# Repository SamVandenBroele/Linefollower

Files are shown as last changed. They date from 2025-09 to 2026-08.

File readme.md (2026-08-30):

# Line Follower Robot

Dit project bevat het ontwerp en de realisatie van een snelle autonome line-following robot voor het Syntheseproject Automatisering.

Het gerealiseerde prototype is een Plan-B-uitvoering en gebruikt zes analoge reflectiesensoren om een zwarte lijn op een witte ondergrond te volgen.

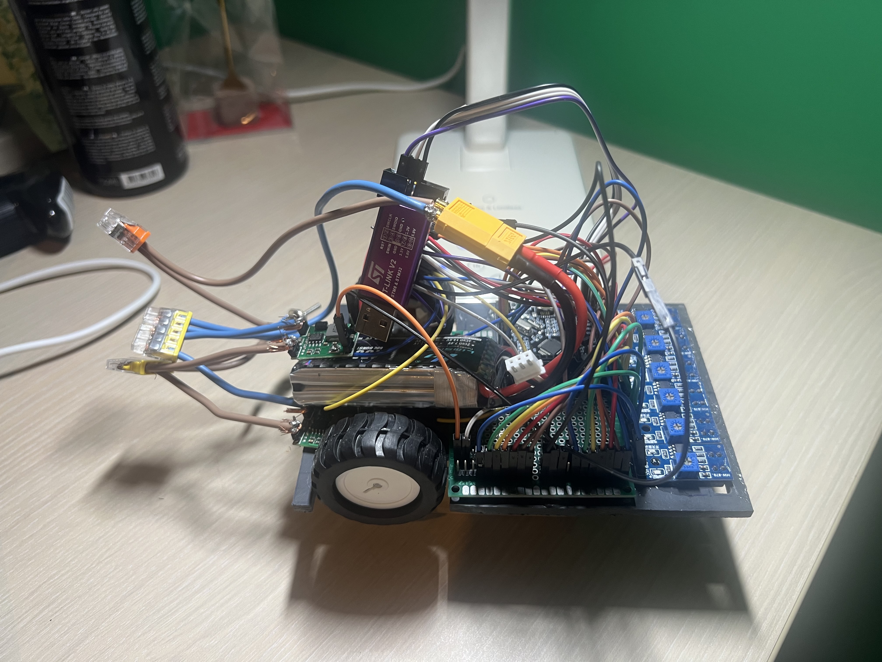
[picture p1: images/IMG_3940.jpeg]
Line Follower Robot


## Specificaties

- Microcontroller: STM32F103C8T6
- Motoren: 2 × GA12-N20, 6 V, 300 rpm
- Motordriver: TB6612FNG dubbele H-brug
- Lijnsensoren: 6 × TCRT5000
- Batterij: 2S LiPo, 7,4 V, 1500 mAh, 45C
- Voedingsregeling: 2 × MP1584EN buckconverter
- Logicaspanning: 3,3 V
- Motorvoeding: 5 V
- Wielen: diameter 44 mm
- Chassis: PVC, 4 mm dik
- Chassisbreedte: 100 mm
- Chassislengte: 147 mm
- Bluetoothmodule: HM-10
- EEPROM: 24LC256

## Werking

De zes TCRT5000-sensoren worden analoog uitgelezen door de ADC van de STM32.

Op basis van de gemeten sensorwaarden wordt de positie van de zwarte lijn bepaald. De STM32 past vervolgens via PWM de snelheid van beide motoren onafhankelijk aan.

De lijncorrectie is proportioneel met de gemeten afwijking van de lijn. In de definitieve software wordt een proportionele correctiefactor van `0,50` gebruikt.

De software maakt onderscheid tussen rechte stukken en bochten. Op rechte stukken wordt een hogere basissnelheid gebruikt en in bochten wordt deze snelheid verlaagd.

Bij detectie van een brede zwarte zone wordt deze als kruispunt beschouwd. De normale lijncorrectie wordt dan tijdelijk uitgeschakeld en beide motoren krijgen dezelfde snelheid, zodat de robot rechtdoor over het kruispunt rijdt.

## Repository

De belangrijkste onderdelen van het project zijn terug te vinden in de volgende mappen:

- `bill of materials` – volledige onderdelenlijst en voedingsverdeling
- `code/finaal` – finale software van de line follower
- `code/proof of concepts/hbridge` – proof of concept van de motorsturing
- `code/proof of concepts/sensor` – proof of concept van de zes lijnsensoren
- `datasheets` – datasheets van de gebruikte componenten
- `gebruiksaanwijzing` – gebruiksaanwijzing van de robot
- `images` – foto's van het gerealiseerde prototype
- `instructable` – stappenplan om de robot na te bouwen
- `technische tekeningen/elektronisch` – elektronisch schema
- `technische tekeningen/mechanisch` – mechanisch ontwerp

## Line-following software

De belangrijkste parameters van de definitieve werkende software zijn:

- snelheid recht stuk: `300`
- snelheid bocht: `150`
- grenswaarde bochtdetectie: `120`
- maximale motorsnelheid in software: `600`
- proportionele correctiefactor: `0,50`
- kruispuntdetectie: minimaal `3` sensoren detecteren zwart
- kruispunt vrijgave: `300` meetcycli

Alle zes lijnsensoren worden door de STM32 uitgelezen.

In de huidige finale software worden de eerste vijf sensoren gebruikt voor de berekening van de lijnpositie en de kruispuntdetectie.

De zesde sensor wordt wel uitgelezen, maar niet meegenomen in deze berekeningen wegens een foutieve hoge meetwaarde op wit in de gemonteerde opstelling.

## Motorsturing

De twee GA12-N20 DC-motoren worden onafhankelijk aangestuurd via de TB6612FNG.

De snelheid van beide motoren wordt geregeld met PWM.

Bij normale lijnvolging wordt de motorsnelheid bepaald volgens:

`motor A = basissnelheid + correctie`

`motor B = basissnelheid - correctie`

waarbij:

`correctie = 0,50 × lijnpositie`

## Kruispunten

Wanneer minimaal drie van de gebruikte lijnsensoren tegelijk zwart detecteren, wordt dit als een brede zwarte zone of kruispunt beschouwd.

Tijdens de kruispuntmodus:

- wordt de normale lijncorrectie tijdelijk uitgeschakeld;
- krijgen beide motoren dezelfde snelheid;
- rijdt de robot rechtdoor;
- wordt pas na meerdere normale meetcycli terug overgeschakeld naar de gewone lijnregeling.

Met de definitieve instellingen neemt het prototype het kruispunt correct rechtdoor.

## Huidige uitvoering

Het Plan-B-prototype wordt in- en uitgeschakeld met een bistabiele tuimelschakelaar.

Als derde steunpunt onder het chassis wordt een LEGO-gezichtje gebruikt dat reeds thuis beschikbaar was en als glijsteun over het parcours beweegt.

De HM-10 Bluetoothmodule en 24LC256 EEPROM zijn voorzien in het elektronische ontwerp, maar worden niet actief gebruikt door de huidige finale lijnvolgsoftware.

Het uiteindelijke prototype heeft geen afzonderlijke START/STOP-drukknop en geen Power-on LED.

De parameters van de lijnregeling werden experimenteel afgesteld op het uiteindelijke prototype.

Met de definitieve instellingen volgt de robot de lijn stabiel, neemt hij het kruispunt correct rechtdoor en kan hij meerdere volledige rondes na elkaar afleggen.

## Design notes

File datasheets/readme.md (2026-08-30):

# Datasheets

Deze map bevat de beschikbare datasheets en technische documentatie van de belangrijkste componenten die gebruikt worden in de Line Following Robot.

## Componenten

De volgende documentatie is opgenomen:

- STM32F103C8T6 microcontroller
- TB6612FNG dubbele motordriver
- TCRT5000 reflectieve optische sensor
- HM-10 Bluetoothmodule
- GA12-N20 6 V 300 rpm DC-reductiemotor
- 24LC256 I²C EEPROM

## TCRT5000-sensormodule

De TCRT5000-sensoren die in dit project gebruikt worden, zijn complete sensormodules met een TCRT5000 reflectieve optische sensor en bijkomende elektronica, waaronder een LM393-comparator.

Er was geen officiële datasheet beschikbaar voor de volledige gebruikte sensormodule.

Daarom is de datasheet van de TCRT5000-sensor zelf opgenomen als technische referentie.

In het uiteindelijke prototype wordt de analoge uitgang A0 van de sensormodule gebruikt.

## GA12-N20 6 V 300 rpm motor

Voor de exacte GA12-N20 6 V 300 rpm motor die in dit project gebruikt wordt, was geen officiële datasheet beschikbaar.

Het opgenomen GA12-N20-document wordt daarom gebruikt als algemene technische referentie voor deze motorfamilie en beschrijft niet noodzakelijk exact de gebruikte 300 rpm-variant.

## MP1584EN buckconverter

Voor de voedingsregeling worden twee instelbare MP1584EN DC-DC step-down buckconverters gebruikt.

De batterijspanning van de 2S LiPo wordt hiermee verlaagd naar:

- 3,3 V voor de 3,3 V-logica;
- 5 V voor de STM32 en de motorvoeding.

De gebruikte modules zijn gebaseerd op de MP1584EN en hebben een instelbare uitgangsspanning.

Er is momenteel geen aparte datasheet van de gebruikte MP1584EN-module opgenomen in deze map.

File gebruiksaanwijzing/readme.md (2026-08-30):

# Gebruiksaanwijzing

Deze gebruiksaanwijzing beschrijft het gebruik van het Plan-B-prototype van de snelle line-following robot.

## Voeding

De robot wordt gevoed door een 2S LiPo-batterij van 7,4 V nominaal.

De batterij wordt via de XT60-connector aangesloten op de robot. De hoofdvoeding wordt in- en uitgeschakeld met de tuimelschakelaar.

De voedingsspanningen worden met twee MP1584EN buckconverters geregeld:

- 5 V voor de STM32 en de motorvoeding via de TB6612FNG
- 3,3 V voor de overige 3,3 V-logica
- de TCRT5000-sensoren worden gevoed via de 3,3 V-uitgang van de STM32

Alle subsystemen gebruiken een gemeenschappelijke GND.

## Inschakelen

1. Plaats de robot op het parcours met de sensoren boven de zwarte lijn.
2. Controleer of de LiPo-batterij correct is aangesloten.
3. Zet de hoofdschakelaar aan.
4. De STM32 start het lijnvolgprogramma automatisch.
5. De robot begint de zwarte lijn te volgen.

## Lijnvolging

De robot beschikt over zes TCRT5000-reflectiesensoren.

De analoge uitgangen van de sensoren worden uitgelezen via de ADC van de STM32F103C8T6.

De software bepaalt aan de hand van de sensorwaarden de positie van de zwarte lijn. Met een proportionele regeling wordt vervolgens het snelheidsverschil tussen de linker- en rechtermotor bepaald.

Op rechte stukken wordt een hogere basissnelheid gebruikt. Wanneer een grotere afwijking van de lijn wordt gemeten, wordt de basissnelheid verlaagd zodat de robot stabieler door bochten kan rijden.

In de huidige software worden vijf van de zes uitgelezen sensoren gebruikt voor de berekening van de lijnpositie. De zesde sensor wordt voorlopig niet meegenomen omdat deze in de huidige opstelling op een witte ondergrond foutief hoge ADC-waarden kan geven.

## Kruispunten

De robot is geprogrammeerd om op een kruispunt rechtdoor te rijden.

Wanneer minstens drie van de gebruikte sensoren gelijktijdig zwart detecteren, wordt dit beschouwd als een brede zwarte zone en wordt de kruispuntmodus geactiveerd.

Tijdens deze modus:

- wordt de normale lijncorrectie tijdelijk uitgeschakeld;
- worden beide motoren met dezelfde snelheid aangestuurd;
- rijdt de robot rechtdoor over het kruispunt.

Wanneer gedurende meerdere opeenvolgende meetcycli opnieuw een normale lijn wordt waargenomen, schakelt de robot automatisch terug naar de normale lijnvolging.

## Motorsturing

De robot gebruikt twee GA12-N20 DC-motoren.

Beide motoren worden onafhankelijk aangestuurd via een TB6612FNG dubbele H-brug.

De snelheid van de motoren wordt geregeld met PWM. Door het snelheidsverschil tussen de linker- en rechtermotor aan te passen kan de robot naar links of rechts corrigeren.

## Instellingen

De belangrijkste instellingen van de huidige finale software zijn:

- rechte snelheid: `220`
- bochtsnelheid: `150`
- bochtdrempel: `120`
- maximale motorsnelheid: `600`
- proportionele correctiefactor: `0,75`
- kruispuntdetectie: minimaal `3` zwarte sensoren

Deze waarden zijn experimenteel afgestemd op het Plan-B-prototype en het gebruikte testparcours.

## Uitschakelen

Na gebruik wordt de robot uitgeschakeld met de hoofdschakelaar.

Wanneer de robot langere tijd niet gebruikt wordt, wordt de LiPo-batterij losgekoppeld van de robot.

## LiPo-batterij

Voor het opladen van de 2S LiPo-batterij moet een geschikte LiPo-balanslader gebruikt worden.

De gebruikte batterij heeft:

- nominale spanning: 7,4 V
- volledig geladen spanning: 8,4 V
- capaciteit: 1500 mAh
- ontlaadfactor: 45C

Een beschadigde of opgezwollen LiPo-batterij mag niet gebruikt of opgeladen worden.

## Huidige beperkingen

De HM-10 Bluetoothmodule, EEPROM en externe START/STOP-functionaliteit zijn voorzien in het elektronische ontwerp, maar zijn niet geïntegreerd in de huidige finale lijnvolgsoftware.

Er wordt in het huidige Plan-B-prototype geen Power-on LED gebruikt.

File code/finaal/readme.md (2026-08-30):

# Finale code

Deze map bevat de finale software van het Plan-B-prototype van de snelle line-following robot.

De software is geschreven voor de STM32F103C8T6 en verzorgt de uitlezing van de lijnsensoren, de aansturing van beide motoren en de detectie van kruispunten.

## Bestandsstructuur

### Inc

- `sensors.h` – definities en functies voor de lijnsensoren
- `motors.h` – definities en functies voor de motorsturing
- `bluetooth.h` – functies voorzien voor de HM-10 Bluetoothmodule
- `eeprom.h` – functies voorzien voor de 24LC256 EEPROM

### Src

- `main.c` – hoofdprogramma en lijnvolgalgoritme
- `sensors.c` – ADC-uitlezing en berekening van de lijnpositie
- `motors.c` – aansturing van de TB6612FNG en beide motoren
- `bluetooth.c` – functies voor Bluetoothcommunicatie
- `eeprom.c` – functies voor EEPROM-communicatie

## Lijnvolging

De robot gebruikt zes TCRT5000-reflectiesensoren.

Alle zes sensoren worden analoog uitgelezen door de ADC van de STM32.

In de huidige finale lijnregeling worden de eerste vijf sensoren gebruikt voor:

- het berekenen van de lijnpositie;
- het detecteren van een kruispunt.

De zesde sensor wordt wel uitgelezen, maar niet meegenomen in de huidige regeling omdat deze in de gemonteerde opstelling een foutief hoge meetwaarde op wit gaf.

De positie van de zwarte lijn wordt bepaald aan de hand van een gewogen gemiddelde van de sensorwaarden.

Op basis van deze lijnpositie wordt een proportionele correctie berekend:

`correctie = 0,50 × lijnpositie`

De motorsnelheden worden vervolgens bepaald als:

`motor A = basissnelheid + correctie`

`motor B = basissnelheid - correctie`

Hierdoor wordt de robot terug naar het midden van de zwarte lijn gestuurd.

## Snelheidsregeling

De definitieve instellingen zijn:

- snelheid op een recht stuk: `300`
- snelheid in een bocht: `150`
- grenswaarde voor bochtdetectie: `120`
- maximale motorsnelheid in software: `600`
- proportionele correctiefactor: `0,50`

Wanneer de absolute waarde van de lijnpositie groter wordt dan `120`, wordt de lagere bochtsnelheid gebruikt.

Hierdoor rijdt de robot sneller op rechte stukken en trager wanneer een grotere stuurcorrectie nodig is.

## Kruispuntdetectie

Een brede zwarte zone wordt als kruispunt beschouwd wanneer minimaal drie van de gebruikte lijnsensoren tegelijk zwart detecteren.

Wanneer een kruispunt wordt gedetecteerd:

1. wordt de normale lijncorrectie tijdelijk uitgeschakeld;
2. krijgen beide motoren dezelfde snelheid;
3. rijdt de robot rechtdoor over het kruispunt;
4. blijft de kruispuntmodus actief tot opnieuw gedurende meerdere meetcycli een normale lijn wordt waargenomen.

De gebruikte instellingen zijn:

- minimaal aantal zwarte sensoren: `3`
- aantal cycli voor het verlaten van de kruispuntmodus: `300`

## Motorsturing

De twee GA12-N20 DC-motoren worden aangestuurd met een TB6612FNG dubbele H-brug.

De snelheid wordt geregeld met PWM.

De gebruikte aansluitingen zijn:

### Motor A

- PWMA → PA8
- AIN1 → PB13
- AIN2 → PB12

### Motor B

- PWMB → PB3
- BIN1 → PB15
- BIN2 → PA9

### TB6612FNG

- STBY → PB14
- VCC → 3,3 V
- VM → 5 V
- GND → gemeenschappelijke GND

## Sensoren

De gebruikte analoge ingangen zijn:

- S0 → PA0
- S1 → PA1
- S2 → PA4
- S3 → PA5
- S4 → PA6
- S5 → PA7

De zes sensoren worden gevoed via de 3,3 V-uitgang van de STM32.

## Huidige uitvoering

De huidige finale software bevat de werkende functies die nodig zijn voor het Plan-B-prototype:

- analoog uitlezen van zes lijnsensoren;
- bepalen van de lijnpositie;
- proportionele lijncorrectie;
- afzonderlijke PWM-aansturing van beide motoren;
- vertragen in bochten;
- detecteren van kruispunten;
- rechtdoor rijden over kruispunten.

De parameters werden experimenteel afgesteld op het uiteindelijke prototype.

Met de definitieve instellingen `300` voor rechte stukken, `150` voor bochten en een proportionele correctiefactor van `0,50` volgt de robot de lijn stabiel en kan hij meerdere volledige rondes na elkaar afleggen.

Ook het kruispunt wordt met deze instellingen correct rechtdoor genomen.

De HM-10 Bluetoothmodule en 24LC256 EEPROM zijn voorzien in het elektronische ontwerp, maar worden niet actief gebruikt door de huidige finale lijnvolgsoftware.

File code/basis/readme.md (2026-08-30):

# Basisprogramma

Deze map was voorzien voor het basisprogramma waarin verschillende algemene functies van de robot samen geïntegreerd konden worden.

Het oorspronkelijke project voorzag onder andere:

- instelbare parameters via seriële communicatie;
- opslag van parameters in EEPROM;
- START/STOP via een externe interrupt;
- draadloze communicatie.

Deze functies zijn niet volledig samengebracht in één afzonderlijk basisprogramma.

Voor het uiteindelijke Plan-B-prototype werd de ontwikkeling voornamelijk gericht op de essentiële functies voor een werkende line-following robot:

- uitlezen van zes analoge TCRT5000-lijnsensoren;
- aansturen van twee DC-motoren via de TB6612FNG;
- PWM-snelheidsregeling;
- berekenen van de lijnpositie;
- corrigeren van de rijrichting;
- detecteren en rechtdoor rijden op kruispunten.

De daadwerkelijk gebruikte software van het uiteindelijke prototype is terug te vinden in:

`code/finaal`

Afzonderlijke werkende tests van de lijnsensoren en H-brug zijn terug te vinden onder:

`code/proof of concepts`

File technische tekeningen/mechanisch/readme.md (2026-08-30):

# Mechanisch ontwerp

Deze map bevat het mechanische ontwerp van het Plan-B-prototype van de snelle line-following robot.

## Chassis

Het chassis is vervaardigd uit een PVC-plaat.

Belangrijkste afmetingen:

- Materiaal: PVC
- Dikte: 4 mm
- Breedte: 100 mm
- Lengte: 147 mm
- Uitsparingen voor de wielen: 20 × 47 mm
- Opening voor de sensoren: 90 × 5 mm
- Voorste rand: 5 mm
- Achterste rand: 5 mm

## Aandrijving

De robot wordt aangedreven door twee GA12-N20 DC-reductiemotoren van 6 V en 300 rpm.

Op beide motoren is een rubberen wiel met een diameter van 44 mm gemonteerd.

## Lijnsensoren

Aan de voorzijde van het chassis zijn zes TCRT5000-reflectiesensoren naast elkaar geplaatst.

De sensoren zijn naar de ondergrond gericht en worden gebruikt om de zwarte lijn op de witte ondergrond te detecteren.

## Elektronica

Op het chassis zijn onder andere de volgende onderdelen geplaatst:

- STM32F103C8T6 development board
- TB6612FNG dubbele H-brug
- twee MP1584EN buckconverters
- 2S LiPo-batterij
- HM-10 Bluetoothmodule
- 24LC256 EEPROM
- prototypeprintplaat
- zes TCRT5000-lijnsensoren

## Derde steunpunt

Als derde steunpunt onder het chassis wordt een LEGO-gezichtje gebruikt dat reeds thuis beschikbaar was.

Het LEGO-onderdeel vormt een eenvoudige glijsteun en glijdt tijdens het rijden over het parcours.

## Mechanische tekening

Het bestand `Mechanical_Design.png` toont de afmetingen van het chassis en de voorziene plaatsing van de belangrijkste onderdelen.

De uiteindelijke fysieke plaatsing van kleine elektronische componenten kan licht afwijken van de schematische voorstelling.

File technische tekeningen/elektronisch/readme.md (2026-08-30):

## Elektronisch schema

Het schema bevat:
- STM32F103C8T6
- 6 × TCRT5000 lijnsensor
- TB6612FNG H-brug
- HM-10 Bluetoothmodule
- 24LC256 EEPROM
- START/STOP-drukknop
- 3,3 V en 5 V voedingsregeling
- beide GA12-N20 motoren

De Electrical Rules Check (ERC) geeft 0 overtredingen.

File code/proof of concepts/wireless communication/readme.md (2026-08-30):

# Draadloze communicatie proof of concept

Voor dit project was een proof of concept voor draadloze communicatie voorzien met behulp van een HM-10 Bluetoothmodule.

De HM-10 Bluetoothmodule is fysiek voorzien in het elektronische ontwerp en aangesloten op de STM32 via USART2:

- STM32 PA2 (USART2_TX) → HM-10 RX
- STM32 PA3 (USART2_RX) ← HM-10 TX

Een werkende proof of concept voor draadloze communicatie werd niet gerealiseerd voor het uiteindelijke Plan-B-prototype.

Draadloze communicatie wordt daarom niet gebruikt door de huidige finale lijnvolgsoftware.

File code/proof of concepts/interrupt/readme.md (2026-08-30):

# Start/stop interrupt proof of concept

Voor dit project was een proof of concept voorzien waarbij een START/STOP-drukknop via een hardware-interrupt wordt uitgelezen.

Deze proof of concept werd niet gerealiseerd voor het uiteindelijke Plan-B-prototype.

Het uiteindelijke prototype beschikt niet over een afzonderlijke START/STOP-drukknop. De robot wordt in- en uitgeschakeld met de bistabiele hoofdschakelaar.

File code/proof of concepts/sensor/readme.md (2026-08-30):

# Sensoren proof of concept

## Testresultaten

De zes TCRT5000-lijnsensoren werden afzonderlijk uitgelezen via de 12-bit ADC van de STM32F103C8T6. Hiervoor wordt de analoge uitgang (A0) van iedere sensormodule gebruikt.

### Meting op witte ondergrond

Bij een witte ondergrond werden ADC-waarden tussen ongeveer 200 en 336 gemeten.

### Meting op zwarte ondergrond

Bij een zwarte ondergrond werden ADC-waarden tussen ongeveer 1700 en 3769 gemeten.

### Conclusie

De test toont aan dat alle zes TCRT5000-sensoren onafhankelijk via de ADC kunnen worden uitgelezen. Er is een duidelijk verschil tussen de gemeten waarden op een witte en een zwarte ondergrond.

De STM32F103C8T6 beschikt over een 12-bit ADC met een bereik van 0 tot 4095. De gemeten waarden benutten een groot deel van dit bereik, met waarden tot 3769 op de zwarte ondergrond.

Voor deze proof of concept worden de ruwe ADC-waarden rechtstreeks weergegeven. Er wordt geen normalisatie of interpolatie toegepast.

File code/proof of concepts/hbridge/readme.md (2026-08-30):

# H-Bridge proof of concept

# H-Bridge proof of concept

Deze proof of concept toont aan dat de TB6612FNG dubbele H-brug correct kan worden aangestuurd door de STM32F103C8T6.

## Doel

Het doel van deze test is controleren of:

- beide GA12-N20 DC-motoren kunnen worden aangestuurd;
- beide motoren onafhankelijk kunnen draaien;
- de draairichting softwarematig kan worden gewijzigd;
- de motorsnelheid met PWM kan worden geregeld;
- de STBY-functie van de TB6612FNG correct werkt.

## Gebruikte componenten

- STM32F103C8T6 development board
- TB6612FNG dubbele H-brug
- 2 × GA12-N20 6 V DC-motor, 300 rpm
- 5 V buck converter
- 3,3 V buck converter
- 2S 7,4 V LiPo-batterij

## Aansluitingen

### Motor A

- PWMA → PA8
- AIN1 → PB13
- AIN2 → PB12
- AO1/AO2 → linker motor

### Motor B

- PWMB → PB3
- BIN1 → PB15
- BIN2 → PA9
- BO1/BO2 → rechter motor

### H-brug

- STBY → PB14
- VCC → 3,3 V
- VM → 5 V
- GND → gemeenschappelijke GND

## Werking

De STM32 genereert PWM-signalen voor PWMA en PWMB. Hiermee wordt de gemiddelde spanning over de motoren en dus hun snelheid geregeld.

AIN1/AIN2 en BIN1/BIN2 bepalen de draairichting van respectievelijk motor A en motor B.

Via de STBY-ingang kan de volledige motordriver worden geactiveerd of in standby worden geplaatst.

De software gebruikt een snelheidswaarde van -1000 tot +1000:

- positieve waarde → vooruit;
- negatieve waarde → achteruit;
- 0 → motor gestopt.

## Testresultaat

De proof of concept werd succesvol uitgevoerd.

- Beide motoren draaien.
- Beide motoren kunnen onafhankelijk worden aangestuurd.
- De draairichting kan softwarematig worden gewijzigd.
- De snelheid kan met PWM worden geregeld.
- Beide motoren kunnen gelijktijdig worden aangestuurd.
- De TB6612FNG werkt correct in combinatie met de STM32F103C8T6.

Deze H-brugsturing wordt verder gebruikt in de finale line-following robot.

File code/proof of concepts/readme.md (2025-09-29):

# Proof of Concepts

Een proof of concept is een combinatie van minimale hard- en software om eenvoudig aan te tonen dat iets werkt.  
Proof of concepts kunnen enerzijds als eerste poging dienen om een bepaald onderdeel van het project werkend te krijgen. Anderzijds kunnen ze tijdens het debuggen van het finale project dienen als test om eventuele hardware problemen te elimineren bij onduidelijke problemen.
<br />  
<br />
Een proof of concept bestaat uit
* een elektronisch schema (indien van toepassing)
* minimale code om de voorop gestelde zaken te demonstreren
* minimale uitleg / aandachtspunten
<br />
De elektronische schakelingen van de proof of concepts komen bij voorkeur overeen met deze van de uiteindelijke linefollower, zodat de code zonder aanpassingen op het finale project kan draaien.

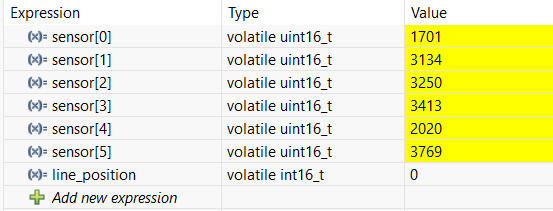
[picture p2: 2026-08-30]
code/proof of concepts/sensor/ZWART.png

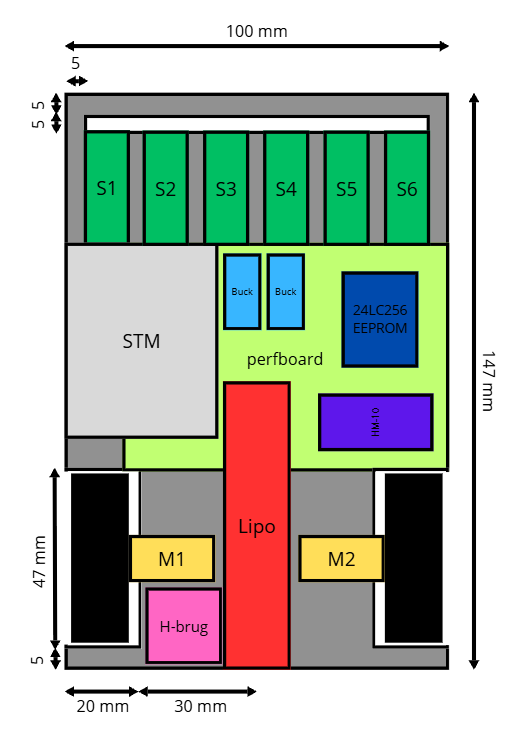
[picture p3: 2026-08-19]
technische tekeningen/mechanisch/Mechanical_Design.png

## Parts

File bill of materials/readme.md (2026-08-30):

# Bill of Materials

Deze Bill of Materials bevat de onderdelen die gebruikt worden voor het Plan-B-prototype van de snelle line-following robot.

| Nr. | Component | Type / specificatie | Aangekocht | Gebruikt | Kostprijs verpakking | Kost in project | Opmerking |
|---:|---|---|---:|---:|---:|---:|---|
| 1 | Dubbele motordriver | TB6612FNG breakoutmodule | 1 | 1 | €4,61 | €4,61 | Stuurt beide GA12-N20 DC-motoren aan |
| 2 | Dupont jumperdraden | 10 cm, diverse stekkertypes | 1 set | n.v.t. | €1,91 | €1,91 | Gebruikt voor het Plan-B-prototype |
| 3 | Infraroodreflectiesensor | TCRT5000-module met VCC, GND, D0 en A0 | 10 | 6 | €3,89 | €2,33 | Zes sensoren gemonteerd; analoge uitgang A0 wordt gebruikt |
| 4 | Microcontrollerbord | STM32F103C8T6 development board | 1 | 1 | €4,69 | €4,69 | Centrale besturing van de robot |
| 5 | Bluetoothmodule | HM-10 BLE 4.0 | 1 | 1 | €3,14 | €3,14 | Fysiek voorzien; draadloze communicatie is niet geïntegreerd in de huidige finale software |
| 6 | Printkroonsteen | KF301, 2-polig, steek 5,0 mm | 50 | ca. 4 | €0,88 | €0,07 | Voor motor- en voedingsaansluitingen |
| 7 | Aan-uitschakelaar | GOOBAY 10013, mini-tuimelschakelaar, ON-OFF, 3 A / 125 V | 2 | 1 | €1,22 | €0,61 | Bistabiele hoofdschakelaar voor het in- en uitschakelen van de batterijvoeding |
| 8 | DC-DC buckconverter | DollaTek MP1584EN, instelbaar, 4,5–28 V ingang, 0,8–20 V uitgang, max. 3 A | 5 | 2 | €4,99 | €2,00 | Eén ingesteld op 3,3 V voor de logica en één ingesteld op 5 V voor STM32 en motorvoeding |
| 9 | Robotwiel | Rubber wiel, diameter 44 mm, geschikt voor N20-as | 2 | 2 | €0,52 | €0,52 | Aandrijfwielen |
| 10 | DC-reductiemotor | GA12-N20, 6 V, 300 rpm | 2 | 2 | €3,60 | €3,60 | Aandrijving van de robot |
| 11 | Batterijconnector | XT60 mannelijk en vrouwelijk | 2 sets | 1 set | €2,38 | €1,19 | Afneembare verbinding tussen LiPo en robot |
| 12 | LiPo-batterij | 2S, 7,4 V, 1500 mAh, 45C | 1 | 1 | €7,91 | €7,91 | Nominaal 7,4 V; maximaal 8,4 V volledig geladen |
| 13 | Pinheaders | 2,54 mm male headers | 10 strips | n.v.t. | €0,68 | €0,68 | Voor modulaire elektrische aansluitingen |
| 14 | Glijsteun | LEGO-gezichtje | - | 1 | - | €0,00 | Reeds in bezit; gebruikt als derde steunpunt onder het chassis |
| 15 | Prototypeprintplaat | Dubbelzijdig protoboard, 6 × 8 cm | 3 | 1 | €2,90 | €0,97 | Printplaat voor de Plan-B-elektronica |
| 16 | Chassismateriaal | PVC-plaat, 4 mm, 100 × 200 mm | 1 | 1 | €4,13 | €4,13 | Basisplaat van de robot |
| 17 | EEPROM | 24LC256-I/P, 256 Kbit (32 KB), I²C, DIP-8 | 2 | 1 | €1,90 | €0,95 | Fysiek voorzien; niet geïntegreerd in de huidige finale lijnvolgsoftware |
| 18 | I²C pull-upweerstand | Metaalfilmweerstand, 4,7 kΩ | 10 | 2 | €0,35 | €0,07 | Pull-upweerstanden voor SDA en SCL van de I²C-bus |
| 19 | Ontkoppelcondensator | Keramisch, 100 nF, KERKO 100N | 10 | 1 | €0,40 | €0,04 | Voedingsontkoppeling bij de EEPROM |
| 20 | Start/stop-drukknop | Momentary tactile pushbutton, 6 × 6 mm | - | 0 | - | €0,00 | Niet gemonteerd op het uiteindelijke Plan-B-prototype |
| 21 | Power-on LED | Losse LED, THT | - | 0 | - | €0,00 | Niet gemonteerd op het uiteindelijke Plan-B-prototype |
| 22 | LED-serieweerstand | 1 kΩ, THT | - | 0 | - | €0,00 | Niet gebruikt op het uiteindelijke Plan-B-prototype |

## Voedingsverdeling

De robot wordt gevoed door een 2S LiPo-batterij van 7,4 V nominaal en maximaal 8,4 V bij volledige lading.

De voedingsverdeling is als volgt:

- LiPo-batterij → hoofdschakelaar → beide buckconverters
- Buckconverter 1 → **3,3 V**
  - TB6612FNG VCC
  - 24LC256 EEPROM
  - HM-10 Bluetoothmodule
  - I²C pull-upweerstanden
- Buckconverter 2 → **5 V**
  - STM32F103C8T6 development board
  - TB6612FNG VM / motorvoeding
- STM32 3,3 V-uitgang → zes TCRT5000-lijnsensoren
- TB6612FNG → beide GA12-N20 DC-motoren
- Alle subsystemen gebruiken een gemeenschappelijke GND

## Bediening

Het huidige Plan-B-prototype wordt in- en uitgeschakeld met een bistabiele tuimelschakelaar.

Als derde steunpunt onder het chassis wordt een LEGO-gezichtje gebruikt dat reeds thuis beschikbaar was. Dit werkt als eenvoudige glijsteun tijdens het rijden.

## Kostenoverzicht

| Omschrijving | Bedrag |
|---|---:|
| Totale aankoopprijs van de in deze BOM opgenomen onderdelen | €50,10 |
| Geschatte kost van gebruikte onderdelen in één robot | ca. €40,22 |

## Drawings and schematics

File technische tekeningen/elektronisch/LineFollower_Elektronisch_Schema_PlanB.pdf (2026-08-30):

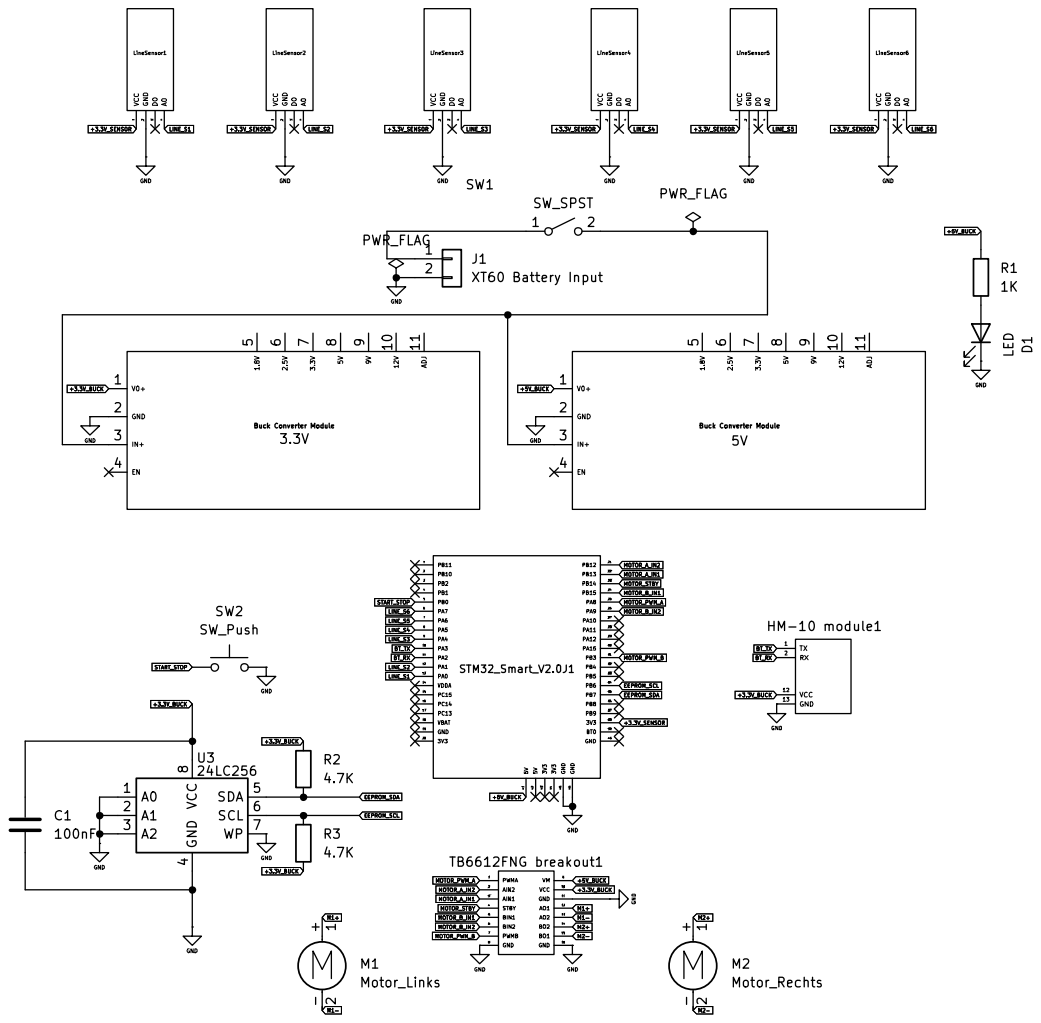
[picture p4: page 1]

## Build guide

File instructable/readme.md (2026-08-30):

# Instructable

Dit stappenplan beschrijft hoe het Plan-B-prototype van de snelle line-following robot kan worden opgebouwd.

Voor de gebruikte componenten wordt verwezen naar de Bill of Materials. Het elektronische schema en de mechanische tekeningen zijn terug te vinden in de map `technische tekeningen`.

## Stap 1 – Verzamel de componenten

Verzamel de componenten uit de Bill of Materials.

De belangrijkste onderdelen zijn:

- STM32F103C8T6 development board
- TB6612FNG dubbele H-brug
- 6 × TCRT5000-reflectiesensor
- 2 × GA12-N20 6 V 300 rpm DC-motor
- 2 × robotwiel van 44 mm
- 2S LiPo-batterij van 7,4 V
- XT60-connector
- 2 × MP1584EN buckconverter
- tuimelschakelaar
- prototypeprintplaat
- PVC-chassis
- Dupont jumperdraden
- HM-10 Bluetoothmodule
- 24LC256 EEPROM
- LEGO-gezichtje als glijsteun

Het LEGO-gezichtje was reeds thuis beschikbaar en wordt gebruikt als derde steunpunt van de robot. Het glijdt tijdens het rijden over het parcours.

## Stap 2 – Bouw het chassis

Maak het chassis uit een PVC-plaat van 4 mm dik.

Monteer vervolgens:

1. beide GA12-N20 motoren;
2. beide aandrijfwielen;
3. het LEGO-gezichtje als glijsteun en derde steunpunt;
4. de sensoropstelling aan de voorzijde;
5. de elektronische componenten op het chassis.

Gebruik de mechanische tekeningen in de repository als referentie voor de afmetingen en plaatsing van de onderdelen.

## Stap 3 – Monteer de lijnsensoren

Monteer zes TCRT5000-sensoren naast elkaar aan de voorzijde van de robot.

De sensoren moeten naar de ondergrond gericht zijn en voldoende dicht boven het parcours geplaatst worden om een duidelijk verschil tussen zwart en wit te meten.

Van iedere TCRT5000-module wordt de analoge uitgang `A0` gebruikt.

De digitale uitgang `D0` wordt niet gebruikt.

## Stap 4 – Bouw de voeding

Sluit de 2S LiPo-batterij via de XT60-connector en de tuimelschakelaar aan op de voedingsverdeling.

Gebruik twee MP1584EN buckconverters.

Stel vóór het aansluiten van de elektronica de uitgangsspanningen met een multimeter af:

- buckconverter 1: 3,3 V
- buckconverter 2: 5 V

De 3,3 V-buckconverter voedt de 3,3 V-logica.

De 5 V-buckconverter voedt de STM32 en de motorvoeding van de TB6612FNG.

De zes TCRT5000-sensoren worden gevoed via de 3,3 V-uitgang van de STM32.

Alle onderdelen moeten een gemeenschappelijke GND hebben.

## Stap 5 – Sluit de STM32 en sensoren aan

Verbind de analoge uitgangen van de zes TCRT5000-sensoren met de STM32:

- sensor S0 → PA0
- sensor S1 → PA1
- sensor S2 → PA4
- sensor S3 → PA5
- sensor S4 → PA6
- sensor S5 → PA7

Verbind de voedingsaansluitingen van de sensoren met de 3,3 V-uitgang van de STM32 en met GND.

## Stap 6 – Sluit de TB6612FNG aan

Sluit de TB6612FNG aan op de STM32.

De gebruikte stuursignalen zijn:

- PWMA → PA8
- AIN1 → PB13
- AIN2 → PB12
- STBY → PB14
- PWMB → PB3
- BIN1 → PB15
- BIN2 → PA9

Sluit:

- VCC aan op 3,3 V van de 3,3 V-buckconverter;
- VM aan op 5 V van de 5 V-buckconverter;
- GND aan op de gemeenschappelijke massa.

Sluit vervolgens beide GA12-N20 motoren aan op de motoruitgangen van de TB6612FNG.

## Stap 7 – Controleer de bedrading

Controleer vóór het inschakelen:

- polariteit van de LiPo-batterij;
- uitgangsspanning van beide buckconverters;
- gemeenschappelijke GND;
- aansluiting van de STM32;
- aansluiting van de TB6612FNG;
- aansluiting van de zes lijnsensoren;
- aansluiting van beide motoren.

Gebruik hiervoor ook het elektronische schema in de repository.

## Stap 8 – Programmeer de STM32

Open het project in STM32CubeIDE.

De finale broncode staat in:

`code/finaal`

De belangrijkste bestanden zijn:

- `main.c`
- `sensors.c`
- `motors.c`
- `sensors.h`
- `motors.h`

Compileer het programma en programmeer de STM32F103C8T6 via SWD met een ST-LINK-programmer.

Voor het programmeren worden gebruikt:

- PA13 → SWDIO
- PA14 → SWCLK
- GND → GND

## Stap 9 – Test de sensoren

Plaats de sensoren eerst boven een witte en daarna boven een zwarte ondergrond.

Controleer of alle zes sensoren een duidelijk verschil in ADC-waarde geven.

De uitgevoerde sensortest is terug te vinden bij:

`code/proof of concepts/sensor`

## Stap 10 – Test de motoren

Controleer afzonderlijk of beide motoren:

- vooruit kunnen draaien;
- afzonderlijk kunnen worden aangestuurd;
- regelbaar zijn in snelheid via PWM.

De uitgevoerde motortest is terug te vinden bij:

`code/proof of concepts/hbridge`

## Stap 11 – Test de lijnvolger

Plaats de robot met de sensoren boven de zwarte lijn.

Schakel de robot in met de tuimelschakelaar.

De STM32 start het programma automatisch en de robot begint de zwarte lijn te volgen.

De software:

- bepaalt de positie van de zwarte lijn;
- corrigeert de snelheid van beide motoren;
- verlaagt de snelheid in bochten;
- detecteert brede zwarte zones als kruispunt;
- probeert op een kruispunt rechtdoor te rijden.

## Stap 12 – Uitschakelen

Schakel de robot na gebruik uit met de tuimelschakelaar.

Koppel de LiPo-batterij los wanneer de robot langere tijd niet gebruikt wordt.

## Opmerking

Het huidige Plan-B-prototype heeft geen afzonderlijke START/STOP-drukknop en geen Power-on LED.

Als derde steunpunt wordt een LEGO-gezichtje gebruikt dat reeds thuis beschikbaar was. Dit onderdeel dient als eenvoudige glijsteun onder het chassis.

De HM-10 Bluetoothmodule en 24LC256 EEPROM zijn voorzien in het elektronische ontwerp, maar zijn niet geïntegreerd in de huidige finale lijnvolgsoftware.

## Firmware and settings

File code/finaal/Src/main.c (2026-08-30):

#include <stdint.h>

#include "sensors.h"
#include "motors.h"


/* =========================================================
   STM32F103C8T6 - LINE FOLLOWER

   LIJNVOLGER MET ROBUUSTE KRUISPUNTDETECTIE

   - normale lijnvolging
   - vertragen in bochten
   - kruispunt detecteren
   - kruispuntmodus vasthouden
   - altijd rechtdoor over kruispunt
   ========================================================= */


/* =========================================================
   INSTELLINGEN
   ========================================================= */

#define STRAIGHT_SPEED          300
#define CURVE_SPEED             150
#define CURVE_THRESHOLD         120

#define MAX_MOTOR_SPEED         600

/*
 * Vanaf 3 zwarte sensoren vermoeden we een kruispunt.
 */
#define CROSS_SENSOR_COUNT      3

/*
 * Na het detecteren van een kruispunt moet de robot
 * gedurende een aantal meetcycli weer een gewone lijn
 * zien voordat de kruispuntmodus wordt verlaten.
 */
#define CROSS_CLEAR_COUNT       300


/* =========================================================
   GLOBAL VARIABLES
   ========================================================= */

volatile int16_t line_position = 0;
volatile int16_t correction = 0;

volatile int16_t base_speed = 0;

volatile int16_t motor_a_speed = 0;
volatile int16_t motor_b_speed = 0;

volatile uint8_t black_sensor_count = 0;

volatile uint8_t crossing_mode = 0;
volatile uint16_t crossing_clear_counter = 0;


/* =========================================================
   MAIN
   ========================================================= */

int main(void)
{
    /* Sensoren initialiseren */
    Sensors_Init();

    /* Motorsturing initialiseren */
    Motors_Init();

    /* TB6612 inschakelen */
    Motors_Enable();

    /* Eerst stilstaan */
    Motors_Stop();


    /* =====================================================
       MAIN LOOP
       ===================================================== */

    while (1)
    {
        /* -------------------------------------------------
           Sensoren uitlezen
           ------------------------------------------------- */

        Sensors_ReadAll();


        /* -------------------------------------------------
           Zwarte sensoren tellen

           S5 = sensor[5] blijft voorlopig genegeerd.

           We gebruiken:
           S0
           S1
           S2
           S3
           S4
           ------------------------------------------------- */

        black_sensor_count = 0;

        for (uint8_t i = 0; i < 5; i++)
        {
            if (sensor[i] > LINE_THRESHOLD)
            {
                black_sensor_count++;
            }
        }


        /* =================================================
           KRUISPUNT DETECTEREN
           ================================================= */

        if (crossing_mode == 0)
        {
            /*
             * Kruispunt herkennen.
             *
             * Drie of meer sensoren tegelijk zwart
             * betekent dat de zwarte zone veel breder
             * is dan een normale lijn.
             */
            if (black_sensor_count >= CROSS_SENSOR_COUNT)
            {
                crossing_mode = 1;
                crossing_clear_counter = 0;
            }
        }


        /* =================================================
           KRUISPUNTMODUS
           ================================================= */

        if (crossing_mode == 1)
        {
            /*
             * Tijdens het volledige kruispunt:
             *
             * GEEN lijncorrectie.
             *
             * Beide motoren exact dezelfde snelheid,
             * zodat de robot rechtdoor blijft rijden.
             */

            motor_a_speed = STRAIGHT_SPEED;
            motor_b_speed = STRAIGHT_SPEED;

            MotorA_SetSpeed(motor_a_speed);
            MotorB_SetSpeed(motor_b_speed);


            /* ---------------------------------------------
               Controleren of kruispunt voorbij is
               --------------------------------------------- */

            if (black_sensor_count <= 2)
            {
                /*
                 * We zien weer iets dat op een normale
                 * lijn lijkt.
                 *
                 * Niet onmiddellijk terugschakelen.
                 * Eerst een aantal opeenvolgende cycli
                 * wachten.
                 */

                crossing_clear_counter++;

                if (crossing_clear_counter >= CROSS_CLEAR_COUNT)
                {
                    crossing_mode = 0;
                    crossing_clear_counter = 0;
                }
            }
            else
            {
                /*
                 * Nog altijd brede zwarte zone.
                 */

                crossing_clear_counter = 0;
            }
        }


        /* =================================================
           NORMALE LIJNVOLGING
           ================================================= */

        else
        {
            /* Positie zwarte lijn berekenen */

            line_position = Sensors_GetLinePosition();


            /* ---------------------------------------------
               Snelheid bepalen
               --------------------------------------------- */

            if ((line_position > CURVE_THRESHOLD) ||
                (line_position < -CURVE_THRESHOLD))
            {
                base_speed = CURVE_SPEED;
            }
            else
            {
                base_speed = STRAIGHT_SPEED;
            }


            /* ---------------------------------------------
               P-regeling

               correctie = 50% van lijnpositie
               --------------------------------------------- */

            correction =
                    (int16_t)(((int32_t)line_position) / 2);


            /* ---------------------------------------------
               Motorsnelheden
               --------------------------------------------- */

            motor_a_speed = base_speed + correction;
            motor_b_speed = base_speed - correction;


            /* ---------------------------------------------
               Motor A begrenzen
               --------------------------------------------- */

            if (motor_a_speed > MAX_MOTOR_SPEED)
            {
                motor_a_speed = MAX_MOTOR_SPEED;
            }

            if (motor_a_speed < 0)
            {
                motor_a_speed = 0;
            }


            /* ---------------------------------------------
               Motor B begrenzen
               --------------------------------------------- */

            if (motor_b_speed > MAX_MOTOR_SPEED)
            {
                motor_b_speed = MAX_MOTOR_SPEED;
            }

            if (motor_b_speed < 0)
            {
                motor_b_speed = 0;
            }


            /* ---------------------------------------------
               Motoren aansturen
               --------------------------------------------- */

            MotorA_SetSpeed(motor_a_speed);
            MotorB_SetSpeed(motor_b_speed);
        }
    }
}

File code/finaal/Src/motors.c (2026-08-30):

#include <stdint.h>
#include "motors.h"

/* =========================================================
   REGISTER DEFINITIONS
   ========================================================= */

/* RCC */
#define RCC_APB2ENR    (*(volatile uint32_t *)0x40021018)
#define RCC_APB1ENR    (*(volatile uint32_t *)0x4002101C)

/* AFIO */
#define AFIO_MAPR      (*(volatile uint32_t *)0x40010004)

/* GPIOA */
#define GPIOA_CRH      (*(volatile uint32_t *)0x40010804)
#define GPIOA_BSRR     (*(volatile uint32_t *)0x40010810)
#define GPIOA_BRR      (*(volatile uint32_t *)0x40010814)

/* GPIOB */
#define GPIOB_CRL      (*(volatile uint32_t *)0x40010C00)
#define GPIOB_CRH      (*(volatile uint32_t *)0x40010C04)
#define GPIOB_BSRR     (*(volatile uint32_t *)0x40010C10)
#define GPIOB_BRR      (*(volatile uint32_t *)0x40010C14)

/* TIM1 */
#define TIM1_CR1       (*(volatile uint32_t *)0x40012C00)
#define TIM1_EGR       (*(volatile uint32_t *)0x40012C14)
#define TIM1_CCMR1     (*(volatile uint32_t *)0x40012C18)
#define TIM1_CCER      (*(volatile uint32_t *)0x40012C20)
#define TIM1_PSC       (*(volatile uint32_t *)0x40012C28)
#define TIM1_ARR       (*(volatile uint32_t *)0x40012C2C)
#define TIM1_CCR1      (*(volatile uint32_t *)0x40012C34)
#define TIM1_BDTR      (*(volatile uint32_t *)0x40012C44)

/* TIM2 */
#define TIM2_CR1       (*(volatile uint32_t *)0x40000000)
#define TIM2_EGR       (*(volatile uint32_t *)0x40000014)
#define TIM2_CCMR1     (*(volatile uint32_t *)0x40000018)
#define TIM2_CCER      (*(volatile uint32_t *)0x40000020)
#define TIM2_PSC       (*(volatile uint32_t *)0x40000028)
#define TIM2_ARR       (*(volatile uint32_t *)0x4000002C)
#define TIM2_CCR2      (*(volatile uint32_t *)0x40000038)


/* =========================================================
   MOTOR INITIALISATIE
   ========================================================= */

void Motors_Init(void)
{
    /* Klokken inschakelen */
    RCC_APB2ENR |= (1U << 0);     /* AFIO */
    RCC_APB2ENR |= (1U << 2);     /* GPIOA */
    RCC_APB2ENR |= (1U << 3);     /* GPIOB */
    RCC_APB2ENR |= (1U << 11);    /* TIM1 */

    RCC_APB1ENR |= (1U << 0);     /* TIM2 */


    /* JTAG uitschakelen, SWD behouden */
    AFIO_MAPR &= ~(0x7U << 24);
    AFIO_MAPR |=  (0x2U << 24);


    /*
     * TIM2 partial remap
     * TIM2_CH2 -> PB3
     */
    AFIO_MAPR &= ~(0x3U << 8);
    AFIO_MAPR |=  (0x1U << 8);


    /* -----------------------------------------------------
       TB6612 direction pins
       ----------------------------------------------------- */

    /*
     * PB12 = AIN2
     * PB13 = AIN1
     * PB14 = STBY
     * PB15 = BIN1
     *
     * Output push-pull 2 MHz
     */
    GPIOB_CRH &= ~(0xFFFFU << 16);

    GPIOB_CRH |= (0x2U << 16);
    GPIOB_CRH |= (0x2U << 20);
    GPIOB_CRH |= (0x2U << 24);
    GPIOB_CRH |= (0x2U << 28);


    /* PA9 = BIN2 */
    GPIOA_CRH &= ~(0xFU << 4);
    GPIOA_CRH |=  (0x2U << 4);


    /* -----------------------------------------------------
       PWM pins
       ----------------------------------------------------- */

    /* PA8 -> TIM1_CH1 */
    GPIOA_CRH &= ~(0xFU << 0);
    GPIOA_CRH |=  (0xAU << 0);


    /* PB3 -> TIM2_CH2 */
    GPIOB_CRL &= ~(0xFU << 12);
    GPIOB_CRL |=  (0xAU << 12);


    /* -----------------------------------------------------
       TIM1 PWM - MOTOR A
       ----------------------------------------------------- */

    TIM1_PSC = 7;
    TIM1_ARR = 999;

    /* PWM mode 1 */
    TIM1_CCMR1 &= ~(0x7U << 4);
    TIM1_CCMR1 |=  (0x6U << 4);

    /* Preload */
    TIM1_CCMR1 |= (1U << 3);

    /* Channel 1 enable */
    TIM1_CCER |= (1U << 0);

    /* Main Output Enable */
    TIM1_BDTR |= (1U << 15);

    /* Update */
    TIM1_EGR |= (1U << 0);

    /* Start timer */
    TIM1_CR1 |= (1U << 0);


    /* -----------------------------------------------------
       TIM2 PWM - MOTOR B
       ----------------------------------------------------- */

    TIM2_PSC = 7;
    TIM2_ARR = 999;

    /* PWM mode 1 CH2 */
    TIM2_CCMR1 &= ~(0x7U << 12);
    TIM2_CCMR1 |=  (0x6U << 12);

    /* Preload */
    TIM2_CCMR1 |= (1U << 11);

    /* Channel 2 enable */
    TIM2_CCER |= (1U << 4);

    /* Update */
    TIM2_EGR |= (1U << 0);

    /* Start timer */
    TIM2_CR1 |= (1U << 0);


    /* Motor driver activeren */
    Motors_Enable();

    /* Veilig starten met motoren stil */
    Motors_Stop();
}


/* =========================================================
   MOTOR A
   Positieve snelheid = VOORUIT
   ========================================================= */

void MotorA_SetSpeed(int16_t speed)
{
    if (speed > 1000)
        speed = 1000;

    if (speed < -1000)
        speed = -1000;


    if (speed > 0)
    {
        /* vooruit */
        GPIOB_BRR  = (1U << 13);
        GPIOB_BSRR = (1U << 12);

        TIM1_CCR1 = (uint16_t)speed;
    }

    else if (speed < 0)
    {
        /* achteruit */
        GPIOB_BSRR = (1U << 13);
        GPIOB_BRR  = (1U << 12);

        TIM1_CCR1 = (uint16_t)(-speed);
    }

    else
    {
        /* stop / coast */
        GPIOB_BRR = (1U << 13);
        GPIOB_BRR = (1U << 12);

        TIM1_CCR1 = 0;
    }
}


/* =========================================================
   MOTOR B
   Positieve snelheid = VOORUIT
   ========================================================= */

void MotorB_SetSpeed(int16_t speed)
{
    if (speed > 1000)
        speed = 1000;

    if (speed < -1000)
        speed = -1000;


    if (speed > 0)
    {
        /* vooruit */
        GPIOB_BRR  = (1U << 15);
        GPIOA_BSRR = (1U << 9);

        TIM2_CCR2 = (uint16_t)speed;
    }

    else if (speed < 0)
    {
        /* achteruit */
        GPIOB_BSRR = (1U << 15);
        GPIOA_BRR  = (1U << 9);

        TIM2_CCR2 = (uint16_t)(-speed);
    }

    else
    {
        /* stop / coast */
        GPIOB_BRR = (1U << 15);
        GPIOA_BRR = (1U << 9);

        TIM2_CCR2 = 0;
    }
}


/* =========================================================
   STOP
   ========================================================= */

void Motors_Stop(void)
{
    MotorA_SetSpeed(0);
    MotorB_SetSpeed(0);
}


/* =========================================================
   STANDBY
   ========================================================= */

void Motors_Standby(void)
{
    /* STBY LOW */
    GPIOB_BRR = (1U << 14);
}


/* =========================================================
   ENABLE
   ========================================================= */

void Motors_Enable(void)
{
    /* STBY HIGH */
    GPIOB_BSRR = (1U << 14);
}

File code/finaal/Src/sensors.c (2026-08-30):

#include "sensors.h"


/* =========================================================
   REGISTER DEFINITIONS
   ========================================================= */

/* RCC */
#define RCC_CFGR       (*(volatile uint32_t *)0x40021004)
#define RCC_APB2ENR    (*(volatile uint32_t *)0x40021018)

/* GPIOA */
#define GPIOA_CRL      (*(volatile uint32_t *)0x40010800)

/* ADC1 */
#define ADC1_SR        (*(volatile uint32_t *)0x40012400)
#define ADC1_CR2       (*(volatile uint32_t *)0x40012408)
#define ADC1_SMPR2     (*(volatile uint32_t *)0x40012410)
#define ADC1_SQR1      (*(volatile uint32_t *)0x4001242C)
#define ADC1_SQR3      (*(volatile uint32_t *)0x40012434)
#define ADC1_DR        (*(volatile uint32_t *)0x4001244C)


/* =========================================================
   GLOBAL SENSOR ARRAY
   ========================================================= */

volatile uint16_t sensor[SENSOR_COUNT];


/* =========================================================
   SENSOR INITIALISATION
   ========================================================= */

void Sensors_Init(void)
{
    /* GPIOA clock */
    RCC_APB2ENR |= (1U << 2);

    /* ADC1 clock */
    RCC_APB2ENR |= (1U << 9);


    /* -----------------------------------------------------
       GPIO als analog input
       MODE = 00
       CNF  = 00
       ----------------------------------------------------- */

    /* PA0 -> S0 */
    GPIOA_CRL &= ~(0xFU << 0);

    /* PA1 -> S1 */
    GPIOA_CRL &= ~(0xFU << 4);

    /* PA4 -> S2 */
    GPIOA_CRL &= ~(0xFU << 16);

    /* PA5 -> S3 */
    GPIOA_CRL &= ~(0xFU << 20);

    /* PA6 -> S4 */
    GPIOA_CRL &= ~(0xFU << 24);

    /* PA7 -> S5 */
    GPIOA_CRL &= ~(0xFU << 28);


    /* -----------------------------------------------------
       ADC clock
       ADCPRE = 10
       PCLK2 / 6
       ----------------------------------------------------- */

    RCC_CFGR &= ~(0x3U << 14);
    RCC_CFGR |=  (0x2U << 14);


    /* -----------------------------------------------------
       Sampling time
       ----------------------------------------------------- */

    ADC1_SMPR2 |= (0x7U << 0);   /* Channel 0 */
    ADC1_SMPR2 |= (0x7U << 3);   /* Channel 1 */
    ADC1_SMPR2 |= (0x7U << 12);  /* Channel 4 */
    ADC1_SMPR2 |= (0x7U << 15);  /* Channel 5 */
    ADC1_SMPR2 |= (0x7U << 18);  /* Channel 6 */
    ADC1_SMPR2 |= (0x7U << 21);  /* Channel 7 */


    /* Eén conversie per sequence */
    ADC1_SQR1 = 0;


    /* ADC inschakelen */
    ADC1_CR2 |= (1U << 0);


    /* -----------------------------------------------------
       Software trigger selecteren
       EXTSEL = 111 -> SWSTART
       EXTTRIG = 1
       ----------------------------------------------------- */

    ADC1_CR2 &= ~(0x7U << 17);
    ADC1_CR2 |=  (0x7U << 17);
    ADC1_CR2 |=  (1U << 20);


    /* Kleine wachttijd */
    for (volatile uint32_t i = 0; i < 10000U; i++)
    {
    }


    /* ADC calibration reset */
    ADC1_CR2 |= (1U << 3);

    while (ADC1_CR2 & (1U << 3))
    {
    }


    /* ADC calibreren */
    ADC1_CR2 |= (1U << 2);

    while (ADC1_CR2 & (1U << 2))
    {
    }
}


/* =========================================================
   READ ONE ADC CHANNEL
   ========================================================= */

uint16_t Sensors_ReadADC(uint8_t channel)
{
    /* Selecteer ADC-kanaal */
    ADC1_SQR3 = channel;


    /* Start softwareconversie */
    ADC1_CR2 |= (1U << 22);


    /* Wacht tot End Of Conversion */
    while (!(ADC1_SR & (1U << 1)))
    {
    }


    /* ADC-resultaat teruggeven */
    return (uint16_t)ADC1_DR;
}


/* =========================================================
   READ ALL SIX SENSORS

   Fysieke volgorde:

   LINKS                           RECHTS
   S0   S1   S2   S3   S4   S5
   ========================================================= */

void Sensors_ReadAll(void)
{
    sensor[0] = Sensors_ReadADC(0);  /* S0 -> PA0 */
    sensor[1] = Sensors_ReadADC(1);  /* S1 -> PA1 */
    sensor[2] = Sensors_ReadADC(4);  /* S2 -> PA4 */
    sensor[3] = Sensors_ReadADC(5);  /* S3 -> PA5 */
    sensor[4] = Sensors_ReadADC(6);  /* S4 -> PA6 */
    sensor[5] = Sensors_ReadADC(7);  /* S5 -> PA7 */
}


/* =========================================================
   CALCULATE LINE POSITION
   =========================================================

   Sensorposities:

   S0 = -390
   S1 = -240
   S2 =  -85
   S3 =  +70
   S4 = +240
   S5 = +400

   S5 wordt TIJDELIJK NIET meegenomen
   omdat deze op wit foutief een hoge ADC-waarde geeft.

   S2 + S3 vormen het gewenste midden.

   ========================================================= */

int16_t Sensors_GetLinePosition(void)
{
    static const int16_t position[SENSOR_COUNT] =
    {
        -390,
        -240,
         -85,
          70,
         240,
         400
    };


    static int16_t last_position = 0;

    int32_t weighted_sum = 0;
    uint32_t total_signal = 0;


    /* -----------------------------------------------------
       Alleen S0 t.e.m. S4 gebruiken

       i < 5 betekent:
       sensor[0]
       sensor[1]
       sensor[2]
       sensor[3]
       sensor[4]

       sensor[5] wordt genegeerd.
       ----------------------------------------------------- */

    for (uint8_t i = 0; i < 5; i++)
    {
        /*
         * Wit   = lage ADC-waarde
         * Zwart = hoge ADC-waarde
         */

        if (sensor[i] > LINE_THRESHOLD)
        {
            weighted_sum +=
                    (int32_t)sensor[i] *
                    (int32_t)position[i];

            total_signal += sensor[i];
        }
    }


    /* -----------------------------------------------------
       Geen zwarte lijn gevonden
       ----------------------------------------------------- */

    if (total_signal == 0U)
    {
        return last_position;
    }


    /* -----------------------------------------------------
       Gewogen gemiddelde berekenen
       ----------------------------------------------------- */

    last_position =
            (int16_t)(
                weighted_sum /
                (int32_t)total_signal
            );


    /* -----------------------------------------------------
       Correctie mechanisch midden

       S2 + S3 vormen gewenste middenpositie.
       ----------------------------------------------------- */

    last_position += 163;


    return last_position;
}
